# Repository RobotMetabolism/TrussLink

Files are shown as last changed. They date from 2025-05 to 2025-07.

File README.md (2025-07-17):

# Truss Links - Self-Assembling Truss Robots

This repository contains the resources for building and working with self-assembling truss robots developed as part of the Robot Metabolism project.

For the latest version TrussLinkSimulation and TrussLinkServer, please refer to the linked repositories on [https://robotmetabolism.github.io/](https://robotmetabolism.github.io/).

## Repository Structure

```
.
├── 3D_files/                          # 3D models and mesh files for printing Truss Link components
│   ├── BodyParts/                     
│   ├── ConnectorParts/                
│   └── ExperimentEnvironment/         
├── RM_AprilTagLayoutGen/              # AprilTag generation and detection tools
│   ├── atagmain.py                    # PDF layout generator for AprilTag strips
│   ├── detect_apriltags.py            # AprilTag detection from images/PDFs
│   ├── flipcroptags.py                # Image preprocessing utility
│   ├── maketags.sh                    # Convenience script for tag generation
│   ├── tag36h11_big/                  # Raw AprilTag images
│   ├── tag36h11_big_cropped_flipped/  # Processed AprilTag images
│   └── tags.pdf                       # Example generated tag layout
├── Robot Link Build Guide.docx        # Assembly instructions (Word format)
├── Robot Link Build Guide.pdf         # Assembly instructions (PDF format)
└── TrussLinkFirmware/                 # Embedded firmware for robot links
    ├── flash.sh                       # Firmware flashing script
    ├── src/                           # Source code
    └── README.md                      # Firmware documentation
```

## Components

### 3D Files
Contains 3D models and mesh files for printing the Truss Link components. Use these files with your 3D printer to manufacture the physical robot parts.

### AprilTag Tools
Complete suite for generating and detecting AprilTag visual markers used to track robot links. See `RM_AprilTagLayoutGen/README.md` for detailed usage instructions.

### Build Guide
Step-by-step assembly instructions available in both Word and PDF formats. Follow this guide to assemble your printed components into functional robot links.

### Firmware
Embedded software for the robot links. See `TrussLinkFirmware/README.md` for compilation and flashing instructions.

## Quick Start

1. **3D Print**: Use files in `3D_files/` to print robot components
2. **Assemble**: Follow the `Robot Link Build Guide.pdf` for assembly
3. **Generate Tags**: Use tools in `RM_AprilTagLayoutGen/` to create AprilTags
4. **Program**: Flash firmware from `TrussLinkFirmware/` to your robot links

## Citation
If you use this work in your research, please cite:

```bibtex
@article{
doi:10.1126/sciadv.adu6897,
author = {Philippe Martin Wyder  and Riyaan Bakhda  and Meiqi Zhao  and Quinn A. Booth  and Matthew E. Modi  and Andrew Song  and Simon Kang  and Jiahao Wu  and Priya Patel  and Robert T. Kasumi  and David Yi  and Nihar Niraj Garg  and Pranav Jhunjhunwala  and Siddharth Bhutoria  and Evan H. Tong  and Yuhang Hu  and Judah Goldfeder  and Omer Mustel  and Donghan Kim  and Hod Lipson },
title = {Robot metabolism: Toward machines that can grow by consuming other machines},
journal = {Science Advances},
volume = {11},
number = {29},
pages = {eadu6897},
year = {2025},
doi = {10.1126/sciadv.adu6897},
URL = {https://www.science.org/doi/abs/10.1126/sciadv.adu6897},
eprint = {https://www.science.org/doi/pdf/10.1126/sciadv.adu6897},
abstract = {Biological lifeforms can heal, grow, adapt, and reproduce, which are abilities essential for sustained survival and development. In contrast, robots today are primarily monolithic machines with limited ability to self-repair, physically develop, or incorporate material from their environments. While robot minds rapidly evolve new behaviors through artificial intelligence, their bodies remain closed systems, unable to systematically integrate material to grow or heal. We argue that open-ended physical adaptation is only possible when robots are designed using a small repertoire of simple modules. This allows machines to mechanically adapt by consuming parts from other machines or their surroundings and shed broken components. We demonstrate this principle on a truss modular robot platform. We show how robots can grow bigger, faster, and more capable by consuming materials from their environment and other robots. We suggest that machine metabolic processes like those demonstrated here will be an essential part of any sustained future robot ecology. Robots grow bigger, faster, and more capable by absorbing and integrating material in their environment.}
}

```

```bibtex
@INPROCEEDINGS{10619984,
  author={Wyder, Philippe Martin and Bakhda, Riyaan and Zhao, Meiqi and Booth, Quinn A. and Kang, Simon and Modi, Matthew Ethan and Song, Andrew and Wu, Jiahao and Patel, Priya and Kasumi, Robert T. and Yi, David and Garg, Nihar Niraj and Bhutoria, Siddharth and Tong, Evan H. and Hu, Yuhang and Mustel, Omer and Kim, Donghan and Lipson, Hod},
  booktitle={2024 6th International Conference on Reconfigurable Mechanisms and Robots (ReMAR)}, 
  title={Robot Links: Towards Self-Assembling Truss Robots}, 
  year={2024},
  pages={525-531},
  doi={10.1109/ReMAR61031.2024.10619984}
}
```

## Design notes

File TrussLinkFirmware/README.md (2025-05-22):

# Truss Link Firmware

Firmware for the Particle-based reconfigurable Truss Links (formerly Robot Links), developed as part of the Robot Metabolism and Robot Links research projects. This firmware enables individual links to communicate, calibrate, and execute motion commands as part of a larger truss structure.

## Table of Contents

- [Project Overview](#project-overview)
- [Features](#features)
- [Hardware Requirements](#hardware-requirements)
- [Dependencies](#dependencies)
- [Installation](#installation)
- [Running the Code](#running-the-code)
  - [Compiling](#compiling)
  - [Flashing](#flashing)
- [Code Structure](#code-structure)
- [Communication Protocol](#communication-protocol)
- [Contributing](#contributing)
- [License](#license)
- [Citation](#citation)
- [Acknowledgements](#acknowledgements)

## Project Overview

The `particleTruss` project provides the firmware for modular Truss Links. Each link runs this firmware on a Particle microcontroller, allowing it to:
- Connect to a central server.
- Receive commands for calibration, position control, sinusoidal motion, and sequenced actions (lists).
- Report its status and sensor readings.
- Perform self-calibration of its servo motors.

This firmware is a key component of research into self-assembling and reconfigurable robotic systems.

## Features

- TCP/IP communication with a central server.
- Servo motor control with position feedback.
- Self-calibration routine for servo operational range.
- Execution of various motion commands:
    - Direct position/velocity control.
    - Sinusoidal motion patterns.
    - Pre-programmed sequences of actions (lists).
- Status reporting (position, battery, current command).
- CRC-15 checksum for message integrity.

## Hardware Requirements

- Particle Photon IoT Microcontroller
- Servo motors (Two per link: `srv0` and `srv1`).
- Analog feedback sensors for servo positions.
- Associated driving circuitry for motors and sensors.

## Dependencies

- **Particle Device OS**: The firmware is built against the Particle Device OS. Ensure your device has a compatible OS version.
- **Particle CLI or Workbench**: For compiling and flashing the firmware.
  - Particle CLI: [https://docs.particle.io/getting-started/developer-tools/cli/](https://docs.particle.io/getting-started/developer-tools/cli/)
  - Particle Workbench: [https://docs.particle.io/getting-started/developer-tools/workbench/](https://docs.particle.io/getting-started/developer-tools/workbench/)

This project does not require additional third-party libraries beyond those included with the Particle Device OS, as indicated by the `project.properties` file.

## Installation

1.  **Set up Particle Environment**:
    Ensure you have the Particle CLI installed and configured, or use Particle Workbench. Log in to your Particle account.
    ```bash
    particle login
    ```
2.  **Claim Your Device**:
    If your Particle device is new, claim it to your account:
    ```bash
    particle device add YOUR_DEVICE_ID
    ```
    Or using Particle Workbench's UI.
3.  **Download Repository**:
    Clone or download this repository to your local machine.
    ```bash
    git clone <repository-url>
    cd TrussLinkFirmware
    ```

## Running the Code

### Compiling

You can compile the firmware using the Particle CLI or Particle Workbench.

**Using Particle CLI**:

Navigate to the `TrussLinkFirmware` directory (where `project.properties` is located).

To compile for a specific platform (e.g., `photon`, `argon`):
```bash
particle compile <platform>
````

For example, for a Photon:

```bash
particle compile photon
```

This will produce a `firmware.bin` file in the `target` directory (or a similar directory depending on CLI version).

**Using Particle Workbench**:
Open the `TrussLinkFirmware` folder in VS Code with Particle Workbench installed. Use the "Particle: Compile application (local)" command.

### Flashing

**Prerequisites**:

  - Your Particle device must be connected to your computer via USB and in DFU mode (blinking yellow) for local flashing, or online and connected to the Particle Cloud for cloud flashing.
  - You need the Device ID of your target Particle device.

**Using `flash.sh` script (Recommended for multiple devices)**:
The `flash.sh` script is provided to help flash multiple devices.
*Review and customize `flash.sh` before use.*
The script can be configured to flash a predefined list of device IDs or all currently online devices.
To make it executable:

```bash
chmod +x flash.sh
```

Then run it (ensure you have compiled firmware):

```bash
./flash.sh <path_to_firmware_binary_if_not_defaulting_to_cloud_flash_source>
```

The script currently uses `particle flash` without specifying a binary, implying it will attempt to flash the most recent successfully compiled firmware from the cloud for your user, or you may need to modify it to point to a local `.bin` file for each `particle flash` command (e.g., `particle flash YOUR_DEVICE_ID firmware.bin`). The active line in the script `particle list | egrep "online" | ... | xargs -n1 particle flash` will attempt to flash the latest cloud-compiled firmware to *all* your online devices that match the filter.

**Using Particle CLI (Single Device)**:
To flash a compiled binary (`firmware.bin`) to a specific device via USB:

```bash
particle flash --usb firmware.bin
```

To flash to a specific device via the cloud (device must be online):

```bash
particle flash YOUR_DEVICE_ID firmware.bin
# OR, to flash the most recently compiled cloud firmware:
particle flash YOUR_DEVICE_ID
```

**Using Particle Workbench**:
Use the "Particle: Flash application (local)" or "Particle: Flash application (cloud)" commands.

## Code Structure

The firmware is organized as follows:

  * **`/src` folder**: Contains the source code for the project.
      * `particleTruss.ino` (processed into `particleTruss.cpp`): The main application file containing `setup()` and `loop()` functions. This file orchestrates the overall behavior of the link.
      * `RMLProtocol.h`: Defines the communication protocol structures, message types, and constants used for server-client interaction.
      * `hardware.h`: Manages hardware-specific functions, including servo control, calibration logic, and execution of motion commands.
      * `utility.h`: Provides utility functions, such as device ID retrieval, time synchronization helpers, and mathematical functions.
  * `project.properties`: Specifies project metadata and dependencies.
  * `flash.sh`: A shell script to assist in flashing the firmware to multiple devices.
  * `README.md`: This file.

## Communication Protocol

The device communicates with a server over TCP/IP using a custom binary protocol defined in `RMLProtocol.h`. Key aspects:

  - Messages consist of a header (`MSG_hdr`), a body (specific to message type), and a footer (`MSG_ftr`) containing a CRC-15 checksum.
  - **Message Types (Device -\> Server)**:
      - `U` (Update): Periodic status update.
  - **Message Types (Server -\> Device)**:
      - `H` (Hello): Sent by device upon connection.
      - `T` (Time): Used to send server epoch time for synchronization.
      - `C` (Calibrate): Instructs the device to perform self-calibration.
      - `P` (Position): Command for direct servo positioning with velocity control.
      - `W` (Walk): Command for a walking gait (implementation pending).
      - `S` (Sinusoidal): Command for sinusoidal motion of servos (implementation pending).
      - `L` (List): Sends a sequence of commands to be executed.

Refer to `RMLProtocol.h` for detailed structure definitions.

## Contributing

Contributions to this project are welcome. Please fork the repository and submit a pull request with your changes. Ensure that your code adheres to the existing style and that any new features or fixes are well-documented.

## License

This project is licensed under the MIT License.

## Citation

If you use this code or draw inspiration from the associated research, please cite the following publications:

1.  **For the Reconfigurable Mechanisms and Robots Conference Paper:**

    ```bibtex
    @INPROCEEDINGS{10619984,
      author={Wyder, Philippe Martin and Bakhda, Riyaan and Zhao, Meiqi and Booth, Quinn A. and Kang, Simon and Modi, Matthew Ethan and Song, Andrew and Wu, Jiahao and Patel, Priya and Kasumi, Robert T. and Yi, David and Garg, Nihar Niraj and Bhutoria, Siddharth and Tong, Evan H. and Hu, Yuhang and Mustel, Omer and Kim, Donghan and Lipson, Hod},
      booktitle={2024 6th International Conference on Reconfigurable Mechanisms and Robots (ReMAR)},
      title={Robot Links: Towards Self-Assembling Truss Robots},
      year={2024},
      volume={},
      number={},
      pages={525-531},
      keywords={Self-assembly;Magnetic separation;Sociology;Maintenance engineering;Trajectory;Topology;Sparks},
      doi={10.1109/ReMAR61031.2024.10619984}
    }
    ```

2.  **For the Main Paper on Robot Metabolism:**

    ```bibtex
    @misc{wyder2024robotmetabolismmachinesgrow,
          title={Robot Metabolism: Towards machines that can grow by consuming other machines},
          author={Philippe Martin Wyder and Riyaan Bakhda and Meiqi Zhao and Quinn A. Booth and Matthew E. Modi and Andrew Song and Simon Kang and Jiahao Wu and Priya Patel and Robert T. Kasumi and David Yi and Nihar Niraj Garg and Pranav Jhunjhunwala and Siddharth Bhutoria and Evan H. Tong and Yuhang Hu and Judah Goldfeder and Omer Mustel and Donghan Kim and Hod Lipson},
          year={2024},
          eprint={2411.11192},
          archivePrefix={arXiv},
          primaryClass={cs.RO},
          url={[https://arxiv.org/abs/2411.11192](https://arxiv.org/abs/2411.11192)}
    }
    ```

## Acknowledgements

This work was supported by [mention any funding sources or significant contributors if applicable].
The CRC-15 implementation is credited to [https://github.com/hiharin/snappro\_xboot/blob/master/board/dm3730logic/prod-id/crc-15.c](https://www.google.com/search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) as noted in `RMLProtocol.h`.

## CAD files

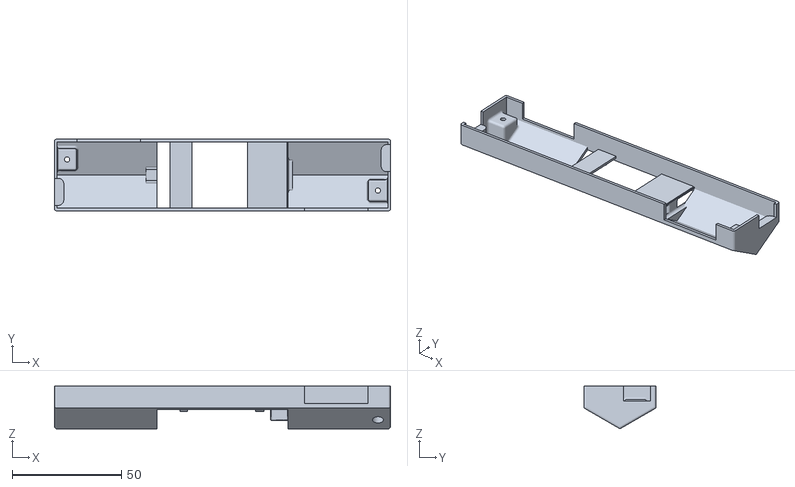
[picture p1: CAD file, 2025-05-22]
3D_files/BodyParts/Body_ParticleSide.obj
153.8 x 32.9 x 19.5

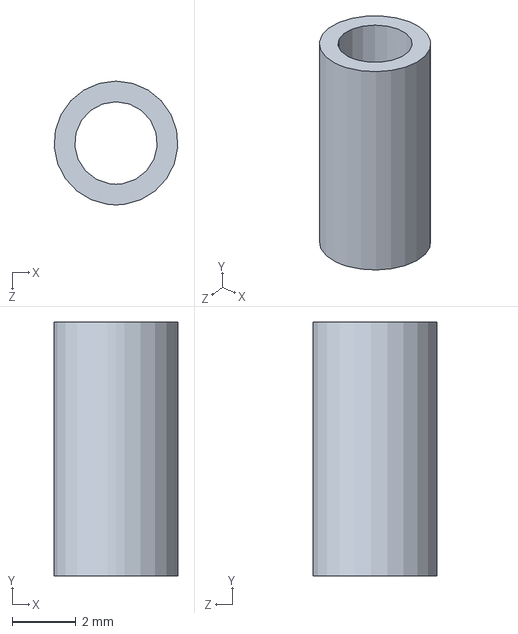
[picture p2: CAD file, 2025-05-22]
3D_files/BodyParts/Solidworks/bushing.SLDPRT
3.89 x 8.00 x 3.90 mm

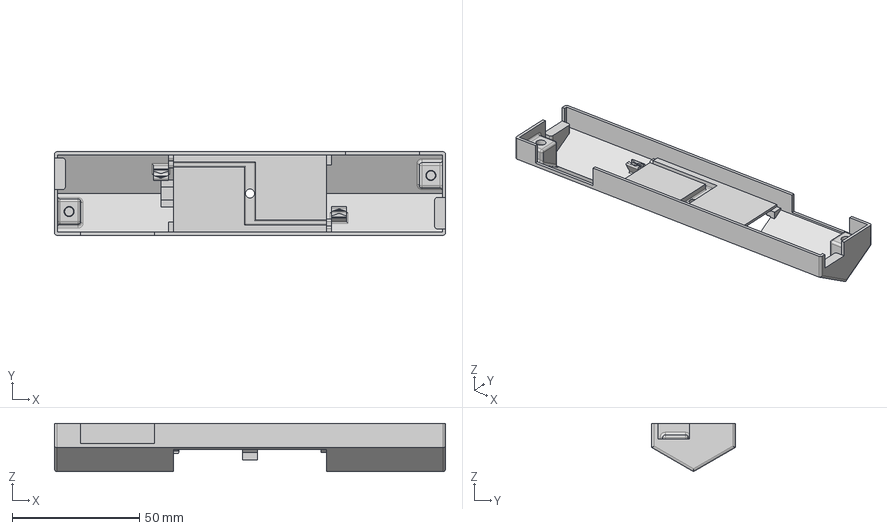
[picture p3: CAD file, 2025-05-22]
3D_files/BodyParts/STEP/Bot_Shell v2.step
153.8 x 32.9 x 19.0 mm

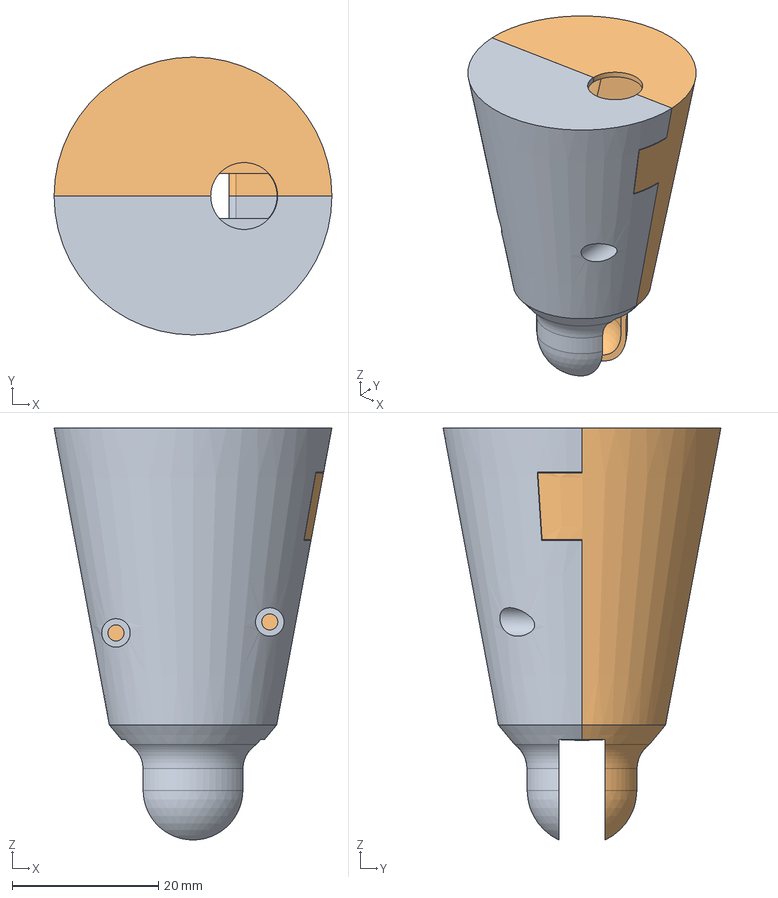
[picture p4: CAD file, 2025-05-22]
3D_files/ConnectorParts/CADFiles/Connector.step
38.0 x 38.0 x 56.3 mm

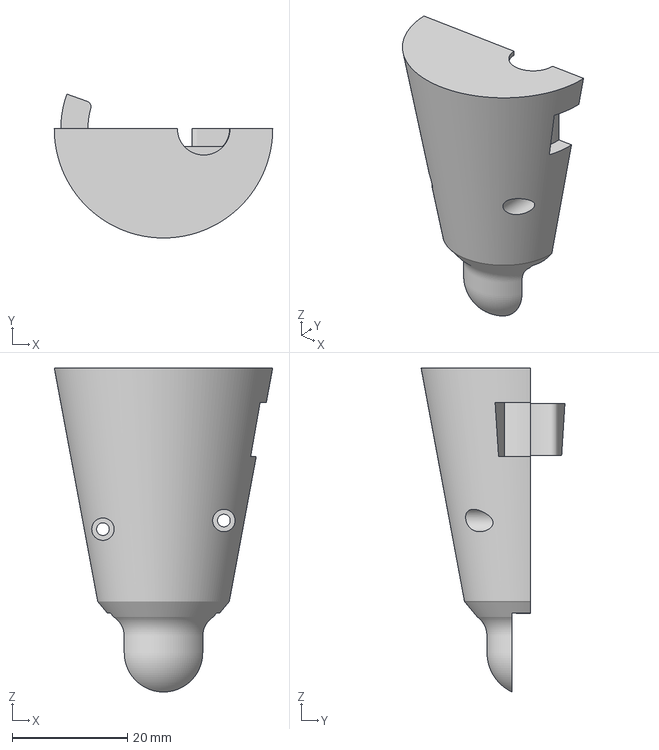
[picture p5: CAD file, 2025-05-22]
3D_files/ConnectorParts/ConnectorShell_L_Chamfer2MM.3mf
38.0 x 25.0 x 56.3 mm

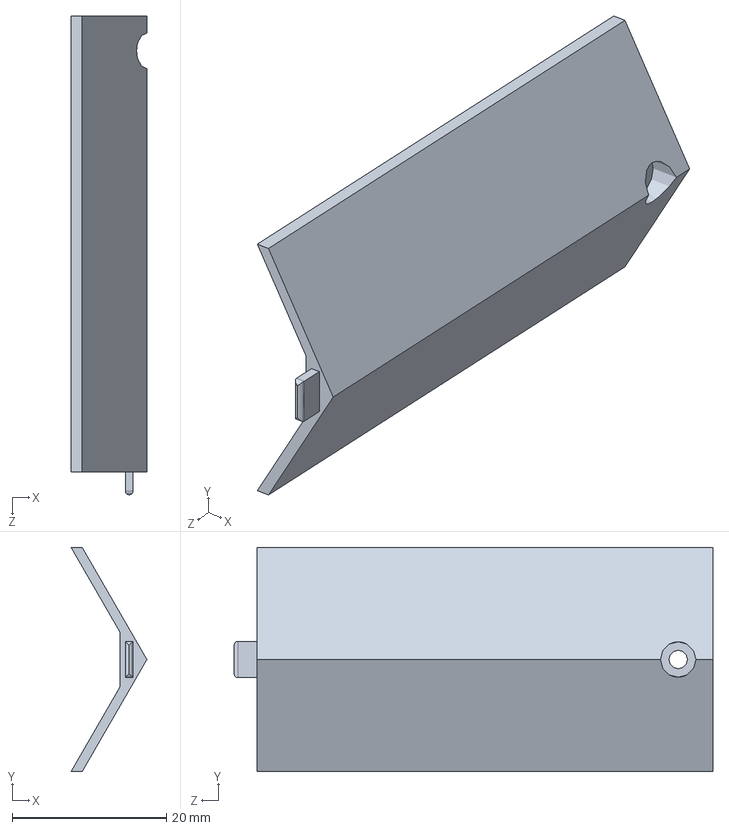
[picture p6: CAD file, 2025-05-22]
3D_files/BodyParts/Solidworks/Cover_up.SLDPRT
9.81 x 29.0 x 62.0 mm

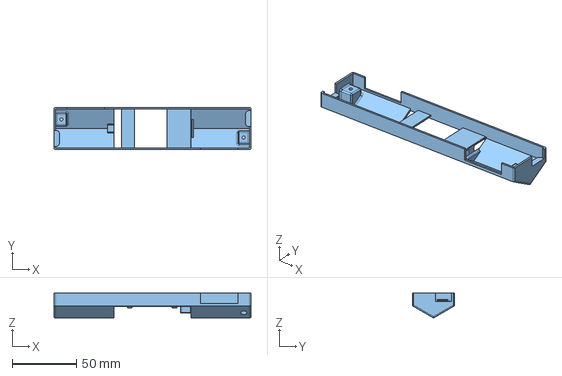
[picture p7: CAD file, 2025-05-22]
3D_files/BodyParts/STEP/Up_Shell v4.step
153.8 x 32.9 x 19.5 mm

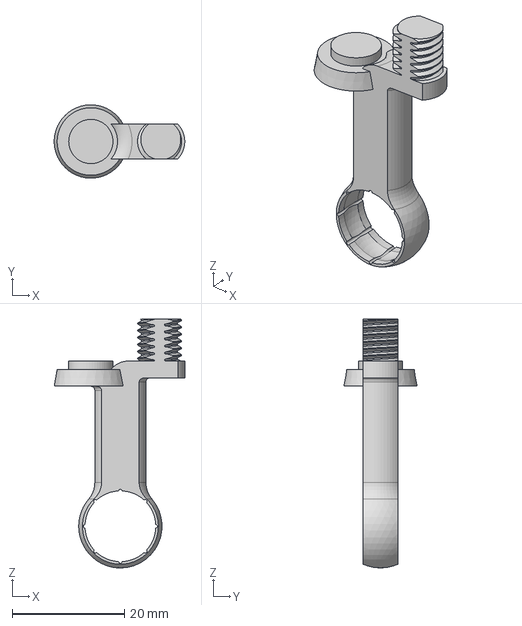
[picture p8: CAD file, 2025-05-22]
3D_files/ConnectorParts/CADFiles/MagHolder.step
23.3 x 13.1 x 44.4 mm

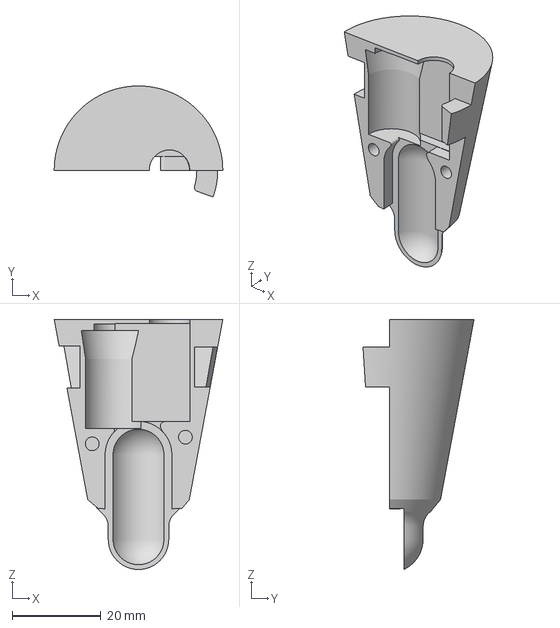
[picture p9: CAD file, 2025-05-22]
3D_files/ConnectorParts/ConnectorShell_R_Chamfer2MM.3mf
38.0 x 25.0 x 56.3 mm

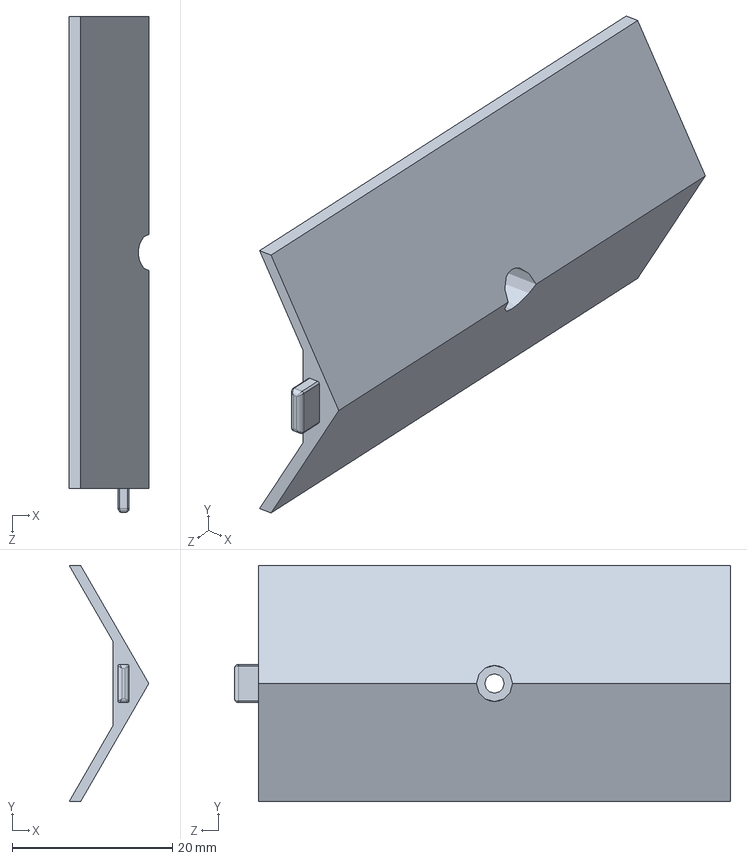
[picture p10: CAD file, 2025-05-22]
3D_files/BodyParts/Solidworks/Cover_bot.SLDPRT
9.96 x 29.5 x 62.0 mm

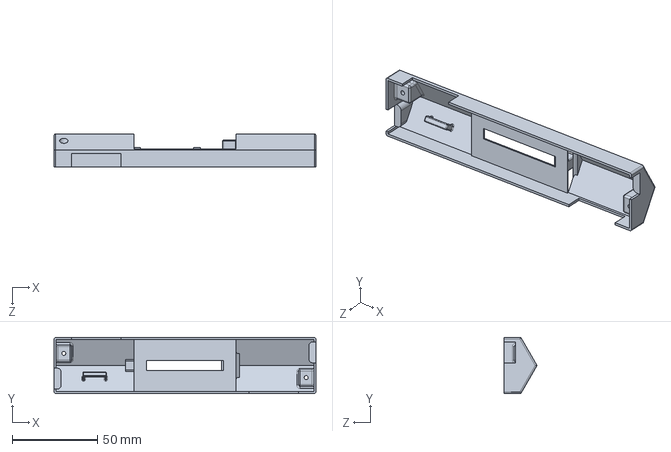
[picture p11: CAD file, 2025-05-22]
3D_files/BodyParts/Solidworks/Up_Shell.SLDPRT
153.8 x 32.9 x 19.5 mm

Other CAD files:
3D_files/BodyParts/Body_BatterySide.obj
3D_files/BodyParts/Solidworks/Bot_Shell.SLDPRT
3D_files/ConnectorParts/MagHolder_2mm_EXT_NonRev090822.3mf
3D_files/BodyParts/Cover_bot.STL
3D_files/BodyParts/Cover_up.STL
3D_files/BodyParts/bushing.STL

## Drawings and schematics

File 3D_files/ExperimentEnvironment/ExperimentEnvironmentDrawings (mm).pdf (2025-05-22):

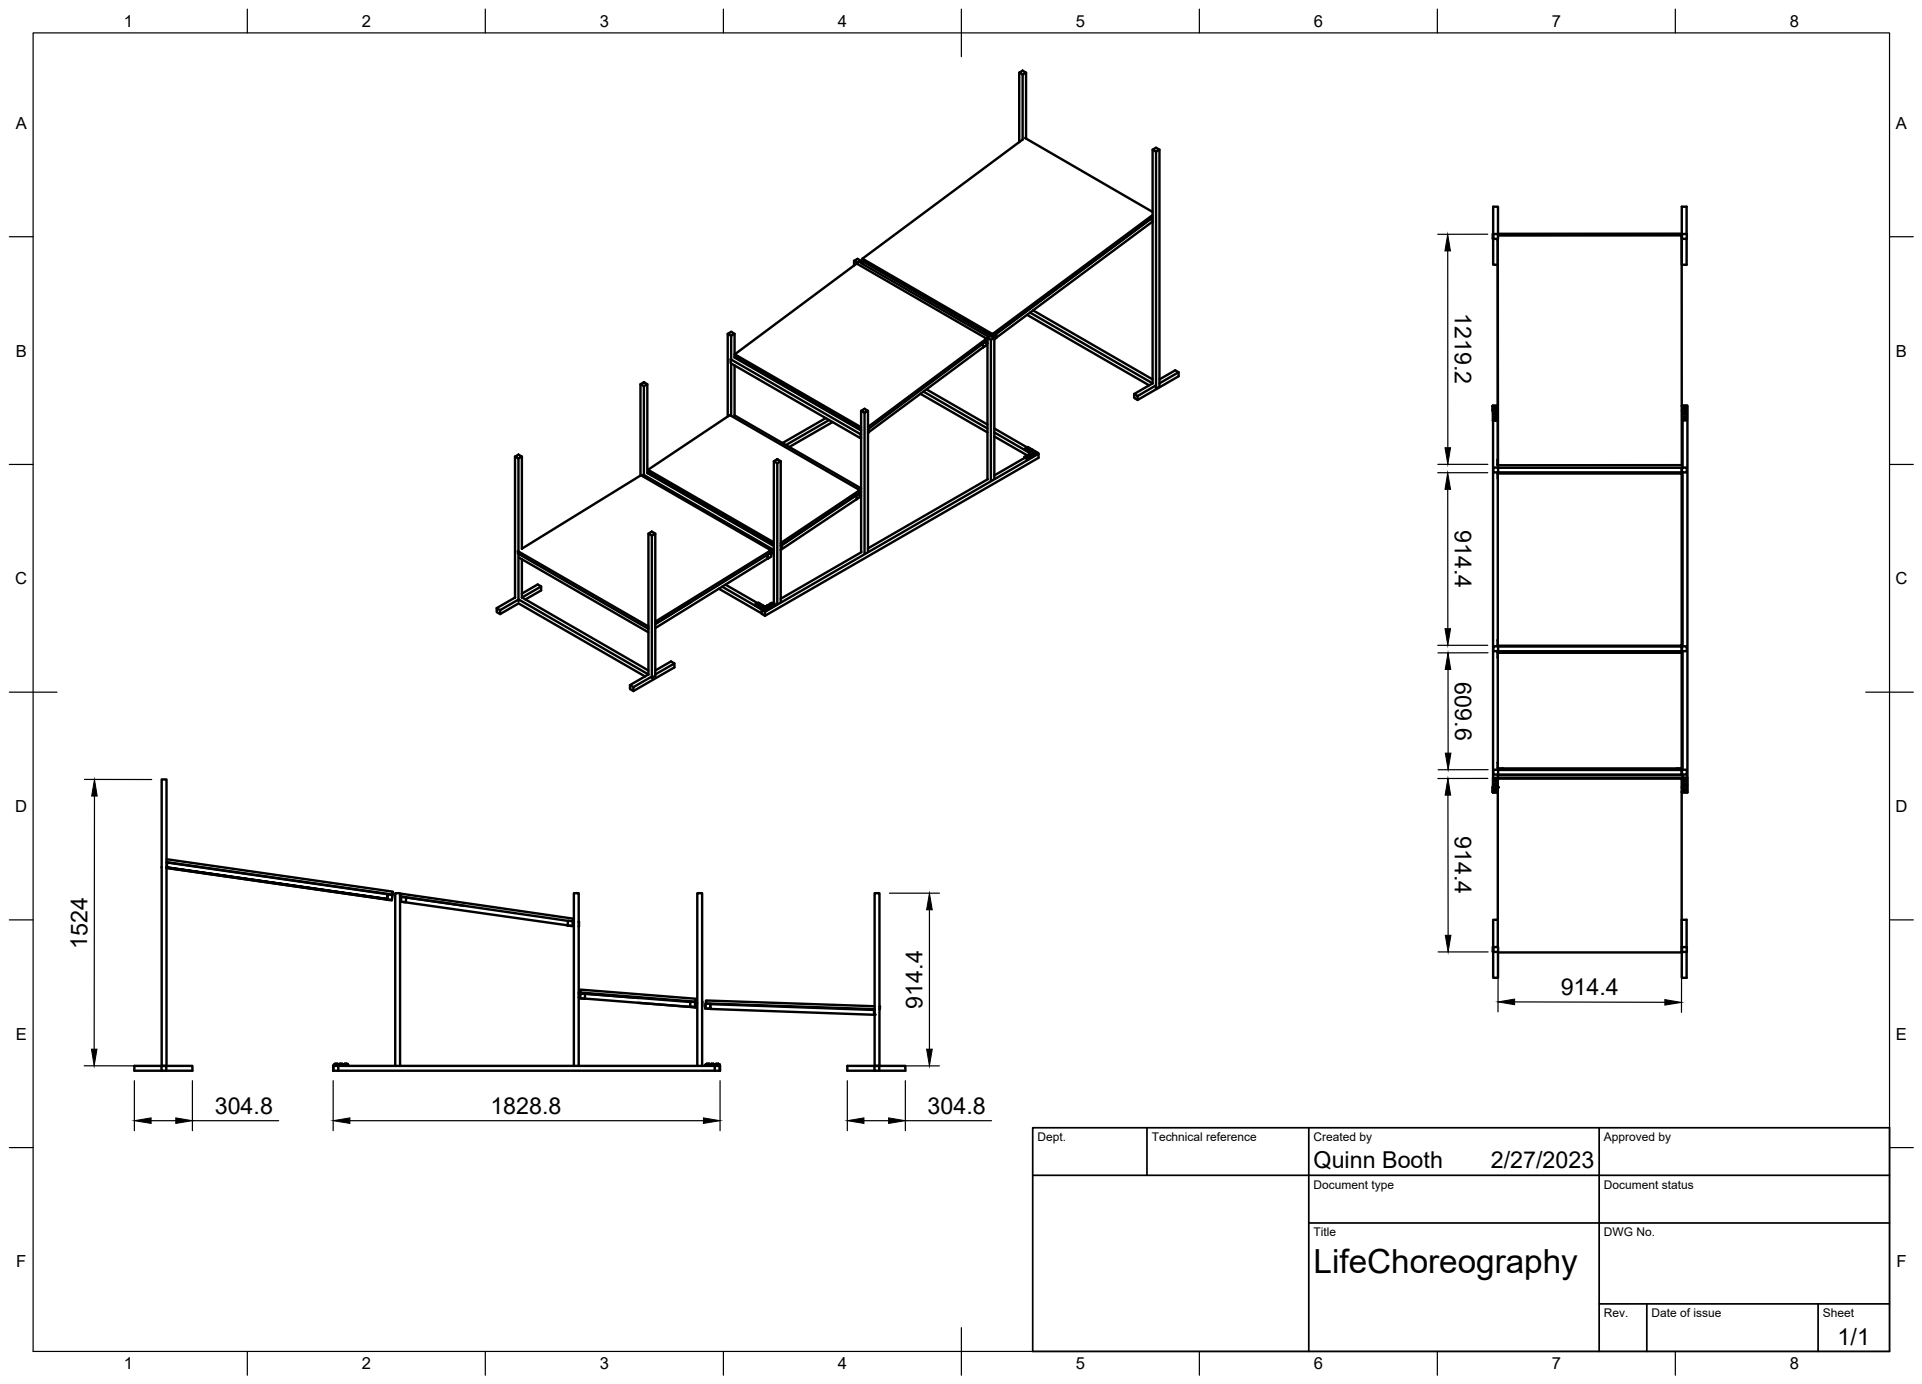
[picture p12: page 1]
Title; DWG No.; Rev.; Date of issue; Sheet; Quinn Booth 914.4

Dept. | Technical reference | Created by 2/27/2023 | Approved by

Document type | Document status

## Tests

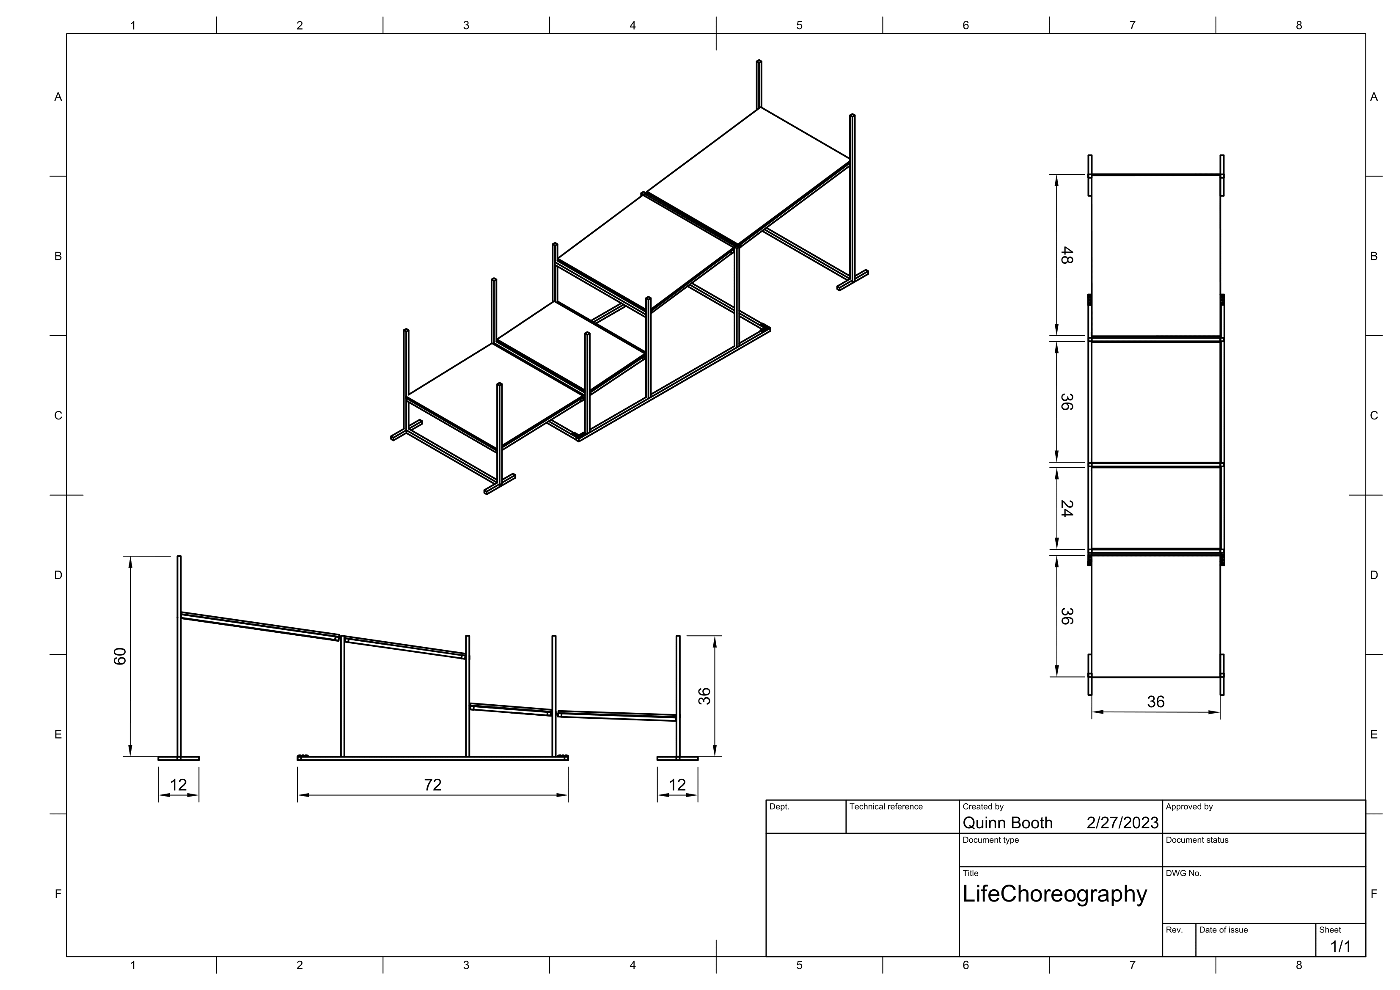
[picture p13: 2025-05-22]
3D_files/ExperimentEnvironment/ExperimentEnvironmentDrawings (in).png

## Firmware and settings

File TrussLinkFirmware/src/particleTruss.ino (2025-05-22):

#include "utility.h"
#include "hardware.h"

//////////////////////////////////////// Setup //////////////////////////////////////////////

SYSTEM_THREAD(ENABLED);
int status_led = D7;
TCPClient server;

unsigned char DEVICE_ID                 = 0;
time_t LAST_UPDATE_TIME                 = 0;
int UPDATE_FREQUENCY                    = 1;
unsigned short CURRENT_COMMAND_CHECKSUM = 0;

/////////////////// List ///////////////////

int LIST_LOCATION                       = 4;
int LIST_CUMULATIVE_TIME                = 0;

boolean RUNNING_LIST = false;

////////////// Initialization //////////////

void setup(){

    //////// Hardware Setup ////////

    Serial.begin(9600);
    DEVICE_ID = get_device_id();
    status.device_status = 'B';

    pinMode(status_led, OUTPUT);
    device.srv0.attach(SERVO_0_D);
    device.srv1.attach(SERVO_1_D);
    Serial.println("Attached Servos");

    updateStatus();

    /// Contract Link on start up ///

    status.srv0_pos = 20;
    status.srv1_pos = 20;
    int timer = millis();
    while (millis() - timer < 10000)
        actuateMotors(2);
}

///////////////////////////////////// Main Code /////////////////////////////////////////////

char prev_device_status;
int bytes_read_header;
int bytes_read_body;
int bytes_read_footer;

// This loop runs constantly and without interruptions
void loop(){

    // Store status at the start to see if it was changed before the end
    prev_device_status = status.device_status;
    updateStatus();

    if(!server.connected()){

        // Indicate via LED: server NOT connected
        digitalWrite(status_led, LOW); 
        status.device_status = 'N';

        // Try to connect to Server
        Serial.println("Connecting to server...");
        server.connect(SERVER_IP, SERVER_PORT);
        waitFor(server.connected, 100);

        // Stop any list commands, reset list_location
        RUNNING_LIST = false;
        LIST_LOCATION = 4;

    } else {

        digitalWrite(status_led, HIGH);

        if(deviceStatusIs('N')){

            // Set status to Hello
            Serial.print("Connected to server! Sending Hello... ");
            status.device_status = 'H';

            // Prepare Hello package
            msg_hdr.get = {MSG_HELLO_LENGTH, 'H'};
            msg_hello.get = {DEVICE_ID, 65};
            msg_ftr.checksum_bytes = crc_15_footer(&msg_hdr, &msg_hello, MSG_HELLO_LENGTH);

            // Write package
            server.write(msg_hdr.bytes,   MSG_HDR_LENGTH);
            server.write(msg_hello.bytes, MSG_HELLO_LENGTH);
            server.write(msg_ftr.bytes,   MSG_FTR_LENGTH);

            // Set status to Ready
            Serial.println("Sent Hello!");
            status.device_status = 'R';

        } else if((bytes_read_header = server.read(msg_hdr.bytes, sizeof(msg_hdr))) != -1){
            
            // Try to recieve command package from server and execute it
            Serial.printf("Got Package of Type %c\n", msg_hdr.get.type);
            
            // List must be interrupted now
            RUNNING_LIST = false;

            switch (msg_hdr.get.type) {
                    case 'T':

                        // Read Time body and checksum
                        bytes_read_body = server.read(msg_epoch.bytes, sizeof(msg_epoch));
                        bytes_read_footer = server.read(msg_ftr.bytes, sizeof(msg_ftr));

                        // Verify checksum
                        if(msg_ftr.checksum_bytes == crc_15_footer(&msg_hdr, &msg_epoch, MSG_EPOCH_LENGTH)){
                            
                            // Checksum correct
                            CURRENT_COMMAND_CHECKSUM = msg_ftr.checksum_bytes;
                            
                            // Sync with second AND millisecond precision (into EPOCHs)
                            SERVER_EPOCH = msg_epoch.get.server_start;
                            int server_time_temp = SERVER_TIME();
                            while(server_time_temp == SERVER_TIME())
                                continue;
                            SERVER_EPOCH_MILLIS = millis() - (SERVER_TIME()*1000);
                        }
                        break;
                    case 'C':

                        // Read Calibration body and checksum
                        bytes_read_body = 0;
                        bytes_read_footer = server.read(msg_ftr.bytes   , sizeof(msg_ftr));

                        // Verify checksum
                        if(msg_ftr.checksum_bytes == crc_15(&msg_hdr, MSG_HDR_LENGTH)){

                            // Checksum correct
                            CURRENT_COMMAND_CHECKSUM = msg_ftr.checksum_bytes;

                            // Set status to trigger calibration
                            status.device_status = 'C';
                        }
                        break;
                    case 'P':

                        // Read PosVel body and checksum
                        bytes_read_body = server.read(msg_position.bytes, sizeof(msg_position));
                        bytes_read_footer = server.read(msg_ftr.bytes   , sizeof(msg_ftr));

                        // Verify checksum
                        if(msg_ftr.checksum_bytes == crc_15_footer(&msg_hdr, &msg_position, MSG_POSITION_LENGTH)){

                            // Checksum correct
                            CURRENT_COMMAND_CHECKSUM = msg_ftr.checksum_bytes;

                            // Set status to trigger PosVel
                            status.device_status = 'P';

                            // Initial time for velocity control
                            initPosVel();
                        }
                        break;
                    case 'W':

                        // Read Walk body and checksum
                        bytes_read_body = server.read(msg_walk.bytes, sizeof(msg_walk));
                        bytes_read_footer = server.read(msg_ftr.bytes   , sizeof(msg_ftr));

                        // Verify checksum
                        if(msg_ftr.checksum_bytes == crc_15_footer(&msg_hdr, &msg_walk, MSG_WALK_LENGTH)){

                            // Checksum correct
                            CURRENT_COMMAND_CHECKSUM = msg_ftr.checksum_bytes;

                            // Set status to trigger Walk
                            status.device_status = 'W';
                        }
                        break;
                    case 'S':

                        // Read Sinusoidal body and checksum
                        bytes_read_body = server.read(msg_sin.bytes, sizeof(msg_sin));
                        bytes_read_footer = server.read(msg_ftr.bytes, sizeof(msg_ftr));

                        // Verify checksum
                        if(msg_ftr.checksum_bytes == crc_15_footer(&msg_hdr, &msg_sin, MSG_SIN_LENGTH)){

                            // Checksum correct
                            CURRENT_COMMAND_CHECKSUM = msg_ftr.checksum_bytes;

                            // Set status to trigger Sinusoidal
                            status.device_status = 'S';
                        }
                        break;
                    case 'L':

                        // Read List body and checksum
                        bytes_read_body = server.read(msg_list_actual.bytes, msg_hdr.get.length);
                        bytes_read_footer = server.read(msg_ftr.bytes   , sizeof(msg_ftr));

                        // Verify checksum
                        if(msg_ftr.checksum_bytes == crc_15_footer(&msg_hdr, &msg_list_actual, msg_hdr.get.length)){

                            // Checksum correct
                            CURRENT_COMMAND_CHECKSUM = msg_ftr.checksum_bytes;

                            // Initialize List parameters
                            RUNNING_LIST    = true;
                            LIST_LOCATION   = 4;  // first 2 bytes are nr_repeat, next 2 bytes are start_time (short);
                            if(msg_list_actual.get.start_time == 0)    // 0 means start immediately
                                msg_list_actual.get.start_time = Time.now();
                            LIST_CUMULATIVE_TIME = 0;   // 0 seconds have passed cumulatively
                        }
                        break;
            }

            // Force-send update for acknowledgement
            LAST_UPDATE_TIME = -1;
        }
    }

    // This copies the appropriate command from the List bytes into memory and triggers it
    if(RUNNING_LIST){

        // Wait till it is time to read next command from List bytes (*)
        if(msg_list_actual.get.start_time + LIST_CUMULATIVE_TIME < SERVER_TIME()){

            // Copy command header: type and duration
            memcpy(msg_list_subheader.bytes, msg_list_actual.bytes + LIST_LOCATION, 2);
            LIST_LOCATION += 2;
            
            // To write time to next command: for line (*)
            LIST_CUMULATIVE_TIME += msg_list_subheader.get.duration;

            switch (msg_list_subheader.get.type){
                case 'P':
                    // Copy into other struct and update LIST_LOCATION
                    memcpy(msg_position.bytes, msg_list_actual.bytes+LIST_LOCATION, MSG_POSITION_LENGTH);
                    LIST_LOCATION += MSG_POSITION_LENGTH;

                    // Set status to trigger PosVel
                    status.device_status = 'P';
                    initPosVel();
                    break;
                case 'S':
                    // Copy into other struct and update LIST_LOCATION
                    memcpy(msg_sin.bytes, msg_list_actual.bytes+LIST_LOCATION, MSG_SIN_LENGTH);
                    LIST_LOCATION += MSG_SIN_LENGTH;

                    // Set status to trigger PosVel
                    status.device_status = 'S';
                    break;
                case 'E':
                    Serial.printf("Reached E: %d\n", msg_list_actual.get.nr_repeat);

                    if(msg_list_actual.get.nr_repeat == 1){
                        // If this was the last time, stop
                        RUNNING_LIST = false;
                        status.device_status = 'R';
                        Serial.println("Finished List and Loop!!!!");
                    } else if(msg_list_actual.get.nr_repeat > 0){
                        // Decrement counter and restart loop
                        Serial.printf("Looping %d\n", msg_list_actual.get.nr_repeat);
                        msg_list_actual.get.nr_repeat--;
                    }
                    LIST_LOCATION = 4;
                    break;
            }
        }
    }

    // Actuate correct Command according to status
    switch (status.device_status){
        case 'C':
            doCalibrateCommand();
            break;
        case 'P':
            doPosVelCommand();
            break;
        case 'W':
            doWalkCommand();
            break;
        case 'S':
            doSinCommand();
            break;
    }

    // List is waiting till next command starts
    if(RUNNING_LIST && status.device_status == 'R')
        status.device_status = '!';

    // Send update package to server
    if(server.connected() && !deviceStatusIs('N'))
        sendUpdatePackage();
}


void sendUpdatePackage(){
    if(LAST_UPDATE_TIME == -1 || Time.now() - LAST_UPDATE_TIME > UPDATE_FREQUENCY || (prev_device_status != status.device_status)){

        Serial.print("Time since Epoch: ");
        Serial.println(SERVER_TIME());
        Serial.println("Sending update... ");
        Serial.printf("Filled update structs %hi ...\n", CURRENT_COMMAND_CHECKSUM);

        // Prepare Update package
        msg_hdr.get = {MSG_UPDATE_LENGTH,'U'};
        msg_update.get = {
            status.device_status,
            status.srv0_pos,
            status.srv1_pos,
            status.srv0_raw,
            status.srv1_raw,
            status.bat_stat,
            status.srv0_vel,
            status.srv1_vel,
            CURRENT_COMMAND_CHECKSUM
        };
        msg_ftr.checksum_bytes = crc_15_footer(&msg_hdr, &msg_update, MSG_UPDATE_LENGTH);

        // Write package
        server.write(msg_hdr.bytes,     MSG_HDR_LENGTH);
        server.write(msg_update.bytes,  MSG_UPDATE_LENGTH);
        server.write(msg_ftr.bytes,     MSG_FTR_LENGTH);

        // Last update time is now
        LAST_UPDATE_TIME = Time.now();
        Serial.println("Sent update!");
    }
}

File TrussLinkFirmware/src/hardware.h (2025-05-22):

#pragma once

#include "utility.h"
#include "RMLProtocol.h"
#include <math.h>

#define SERVO_0_A A0
#define SERVO_0_D D0
#define SERVO_1_A A1
#define SERVO_1_D D1

#define POS_LOWERBOUND 0
#define POS_UPPERBOUND 100
#define SRV_UNRESPONSIVE_CUTOFF 7
#define MOVING_AVERAGE_PERIOD 16
#define EEPROM_CALIBRATION_ADDR 0
#define CALIBRATION_CHANGE_THRESHOLD 5
#define FORCE_CALIBRATION 0
#define MAX_SPEED 65                   // mm/s (ToDo: Calibrate from empirical data)
#define DETATCH_STROKE_FRACTION 0.25    // fraction of total stroke used by detach mechanism

#define APPROX_CALIBRATION_1000 4096
#define APPROX_CALIBRATION_2000 0


////////////////////////////////////// Primary Functions ////////////////////////////////////////

// initialize robot hardware struct 
struct device_t{
    String device_id_string = System.deviceID();
    unsigned char device_id = 255;
    Servo srv0;
    Servo srv1;
}device;

// returns servo position in mm
int getServoPosition(int servo_number){

    int result = -1;

    if(servo_number == 0)
        result = map(analogRead(SERVO_0_A), 0, 4096, 100, 0);

    if(servo_number == 1)
        result = map(analogRead(SERVO_1_A), 0, 4096, 100, 0);

    // Serial.printf("Read servo %d as %d\n", servo_number, result);

    return result;
}

// set servo positions (takes parameters in mm)
void setServoPosition(int servo_number, int srv_pos){
    if(servo_number == 0)
        device.srv0.writeMicroseconds(map(srv_pos, POS_LOWERBOUND, POS_UPPERBOUND, APPROX_CALIBRATION_1000, APPROX_CALIBRATION_2000));

    if(servo_number == 1)
        device.srv1.writeMicroseconds(map(srv_pos, POS_LOWERBOUND, POS_UPPERBOUND, APPROX_CALIBRATION_1000, APPROX_CALIBRATION_2000));

    // Serial.printf("Moved servo %d to %d\n", servo_number, srv_pos);
}


// Updates the status struct
void updateStatus(){
    status.srv0_raw = getServoPosition(0);
    status.srv1_raw = getServoPosition(1);

    status.bat_stat = (analogRead(A2))/100;
}

void actuateMotors(int tolerance){

    if(getAbsoluteValue(status.srv0_pos - status.srv0_raw) > tolerance){
        if(status.srv0_raw < status.srv0_pos)
            device.srv0.writeMicroseconds(2000);
        else
            device.srv0.writeMicroseconds(1000);
    }

    if(getAbsoluteValue(status.srv1_pos - status.srv1_raw) > tolerance){
        if(status.srv1_raw < status.srv1_pos)
            device.srv1.writeMicroseconds(2000);
        else
            device.srv1.writeMicroseconds(1000);
    }

    delay(5);

    updateStatus();

    device.srv0.writeMicroseconds(map(status.srv0_raw, 0, 100, 1000, 2000));
    device.srv1.writeMicroseconds(map(status.srv1_raw, 0, 100, 1000, 2000));
}

////////////////////////////////////////// Calibration //////////////////////////////////////////

// initialize robot calibration struct
struct srv_calibration_t {
    uint8_t version;
    int srv0_min_ms, srv0_max_ms; 
    int srv1_min_ms, srv1_max_ms;
    int srv0_raw_min, srv0_raw_max;
    int srv1_raw_min, srv1_raw_max;
} srv_calibration;

void runCalibration(){
    int addr = EEPROM_CALIBRATION_ADDR;
    // initialize calibration
    srv_calibration = { 0,
                        1000, 2000, 
                        1000, 2000, 
                        0, 4096, 
                        0, 4096 
                      };

    // set servos to 0
    Serial.println("Set Servo to 1000 and wait for it to get there");
    device.srv0.writeMicroseconds(1000);
    device.srv1.writeMicroseconds(1000);
    status.srv0_pos = 0;
    status.srv1_pos = 0;
    wait_visual(20000);

    // calibration relevant variables
    int srv0_raw_new, srv1_raw_new;
    bool srv0_is_responding = false;
    bool srv1_is_responding = false;
    int srv0_buffer[MOVING_AVERAGE_PERIOD];
    int srv0_buffer_idx = 0;
    int srv0_sum = status.srv0_raw * MOVING_AVERAGE_PERIOD;
    int srv0_avg = status.srv0_raw;
    int srv0_prev_avg = srv0_avg;
    int srv1_buffer[MOVING_AVERAGE_PERIOD];
    int srv1_buffer_idx = 0;
    int srv1_sum = status.srv1_raw * MOVING_AVERAGE_PERIOD;
    int srv1_avg = status.srv1_raw;
    int srv1_prev_avg = srv1_avg;
    int srv0_OOR_counter = 0;
    int srv1_OOR_counter = 0;

    // initialize buffers with initial readings
    status.srv0_raw = analogRead(A0);
    status.srv1_raw = analogRead(A1);
    for (int i = 0; i < MOVING_AVERAGE_PERIOD; i++){
        srv0_buffer[i] = status.srv0_raw;
        srv1_buffer[i] = status.srv1_raw;
    }
    Serial.println("Entering Calibration Loop:\n");
    Serial.printf("Input,\tSRV0_new,\tSRV0,\tSRV1_new,\tSRV1\n"); 
    for (int i = 1000; i < 2001; i+=1){
        device.srv0.writeMicroseconds(i);
        device.srv1.writeMicroseconds(i);
        status.srv0_pos = i;
        status.srv1_pos = i;
        // wait for Servo to go to position
        delay(125);

        // remove previous value
        srv0_sum = srv0_sum - srv0_buffer[srv0_buffer_idx];
        srv1_sum = srv1_sum - srv1_buffer[srv1_buffer_idx];
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
